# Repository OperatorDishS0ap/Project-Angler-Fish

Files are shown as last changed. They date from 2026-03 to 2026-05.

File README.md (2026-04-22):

  
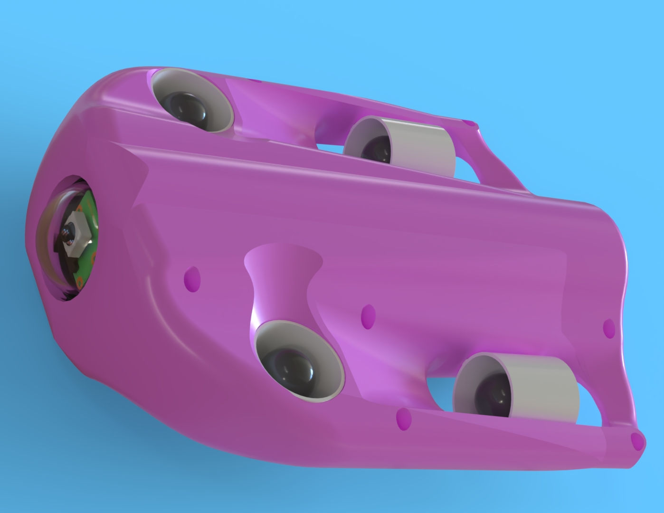
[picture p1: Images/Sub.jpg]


# Technical Details
23.5cm Long X 11cm Wide  
100ft depth rating  
Low-Latency Live Camera View  
Intuitive Control with an Xbox360 Controller 
Temperature and Depth Monitoring
Tethered Via Ethernet

# Introduction
Remotely operated vehicles (ROVs) are widely used for underwater research, inspection, and exploration; however, many commercially available systems remain prohibitively expensive for small research teams, educational institutions, and independent developers. This project explores the feasibility of designing and developing a cost-effective, remotely operated submersible capable of supporting underwater exploration while maintaining essential functionality and reliability.  
The system consists of a tethered ROV that provides four-axis maneuverability and a real-time first-person-view (FPV) video feed for navigation and situational awareness. Communication between the submersible and the surface control station is achieved through an Ethernet tether, enabling bidirectional control signals and continuous live video transmission.  
The project integrates mechanical design, electrical system development, and embedded software to implement propulsion control, sensor monitoring, and remote operation. Testing demonstrates that the vehicle is capable of stable maneuvering and reliable communication with the surface station while delivering continuous video feedback for navigation.  
To promote accessibility and encourage further development, all design files, software, assembly documentation, and technical resources associated with this project are released as open-source materials. These resources allow others to replicate, modify, and expand upon the system using accessible components and tools.   

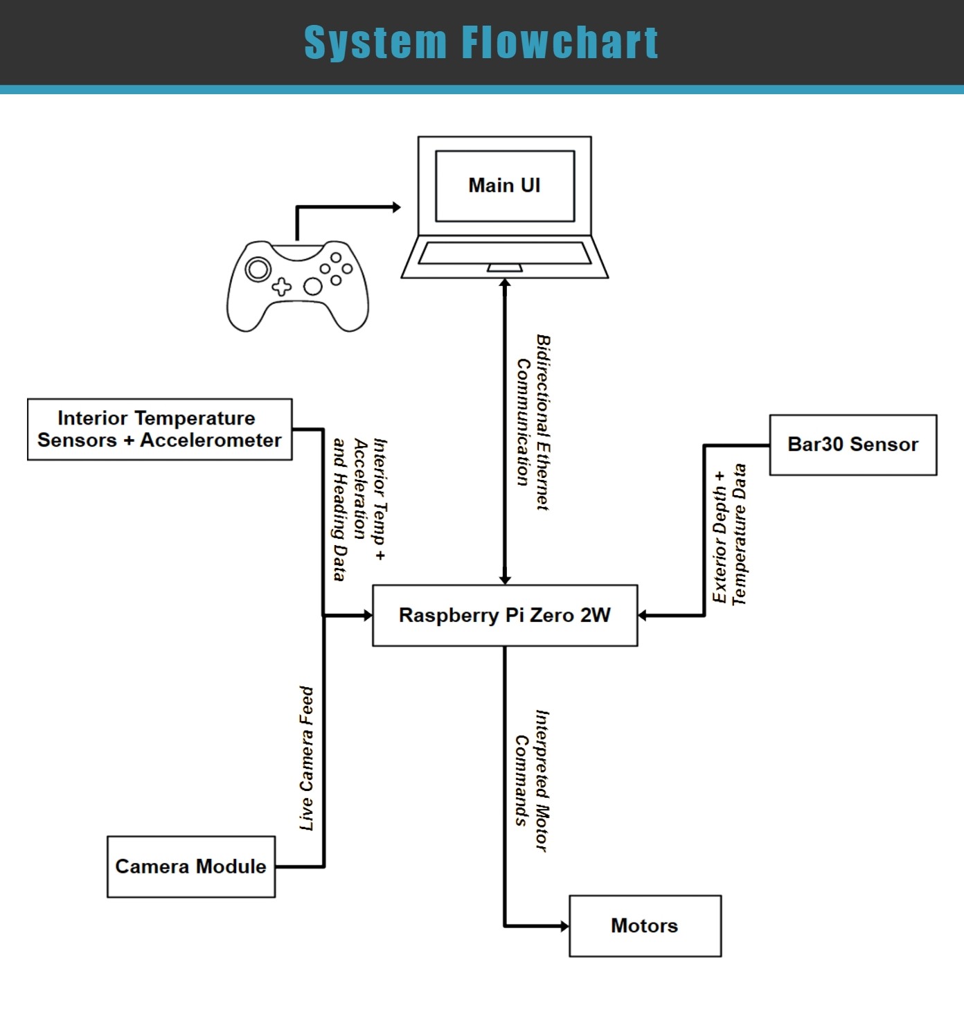
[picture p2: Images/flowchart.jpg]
flowchart
  
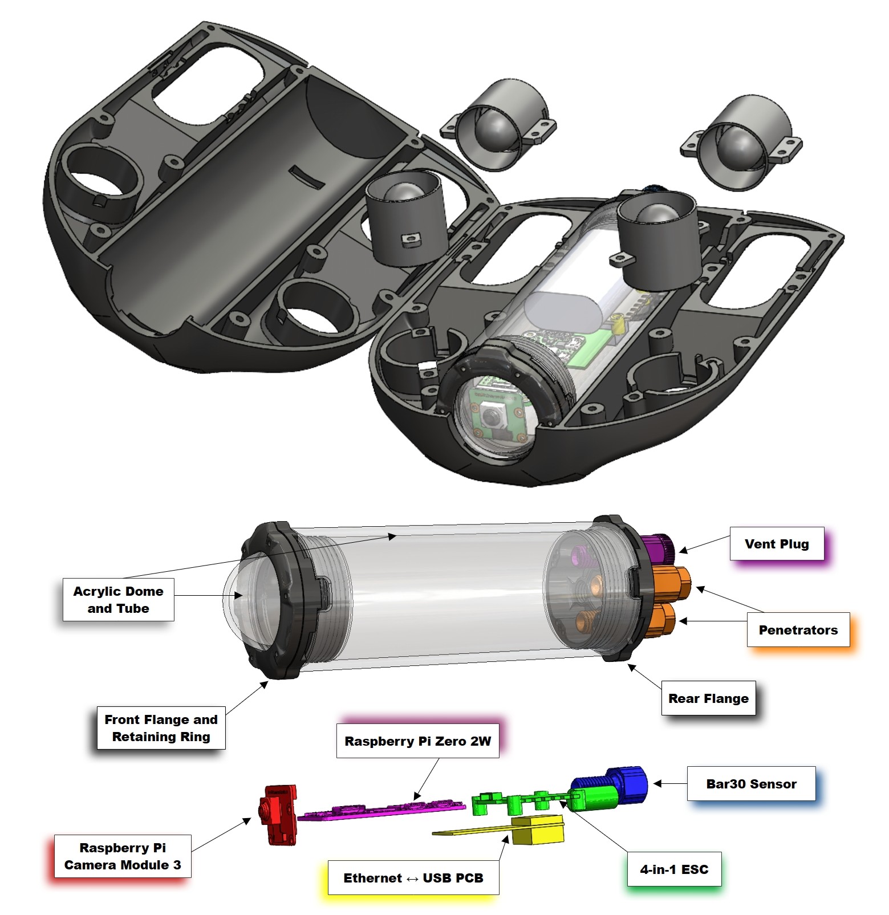
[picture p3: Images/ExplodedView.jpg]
explodedview
  

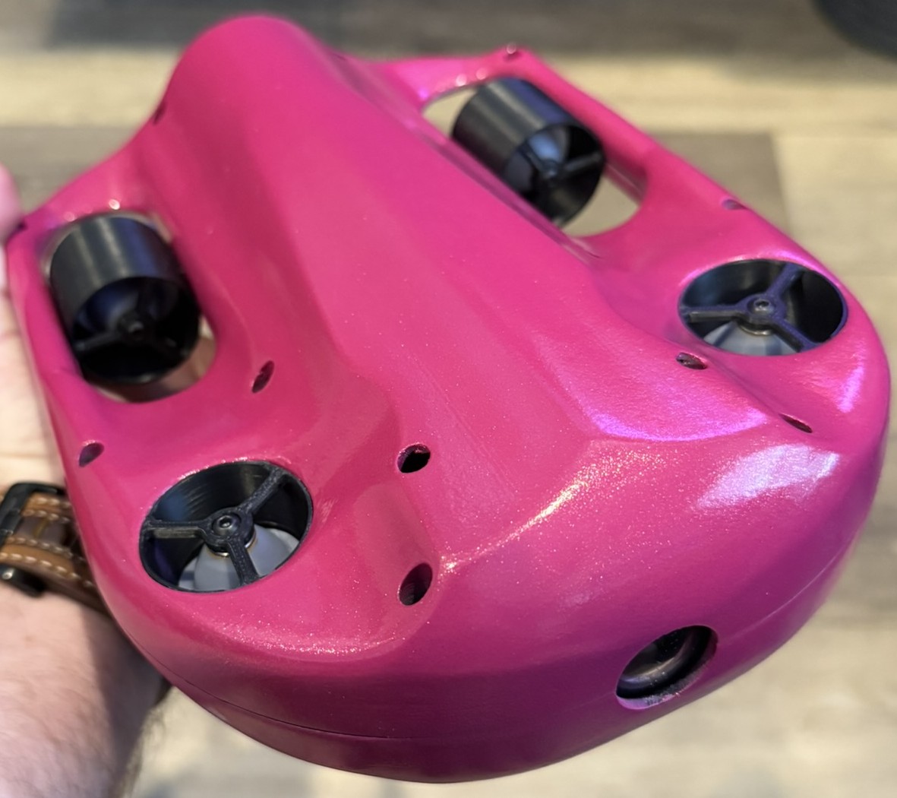
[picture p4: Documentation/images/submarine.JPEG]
Submarine

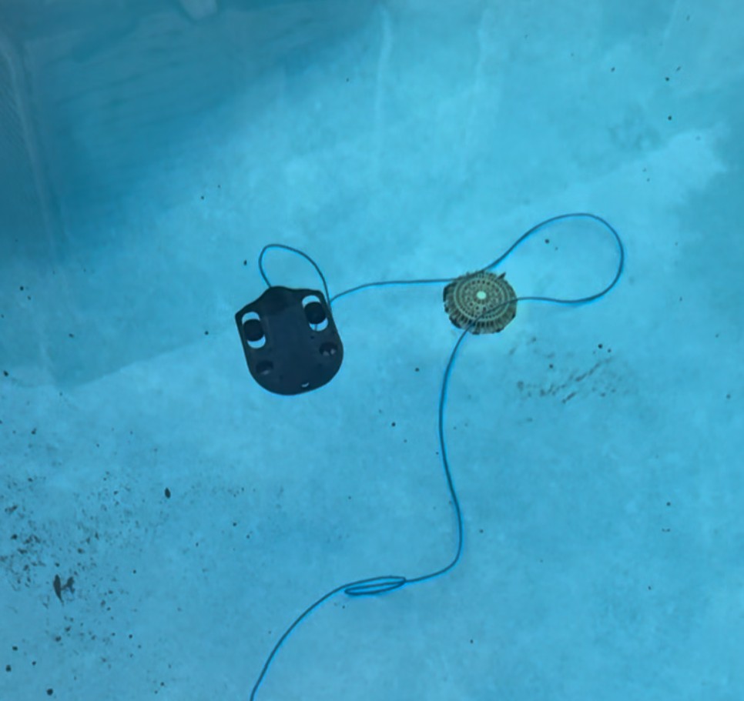
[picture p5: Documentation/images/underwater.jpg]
Submarine in the Pool

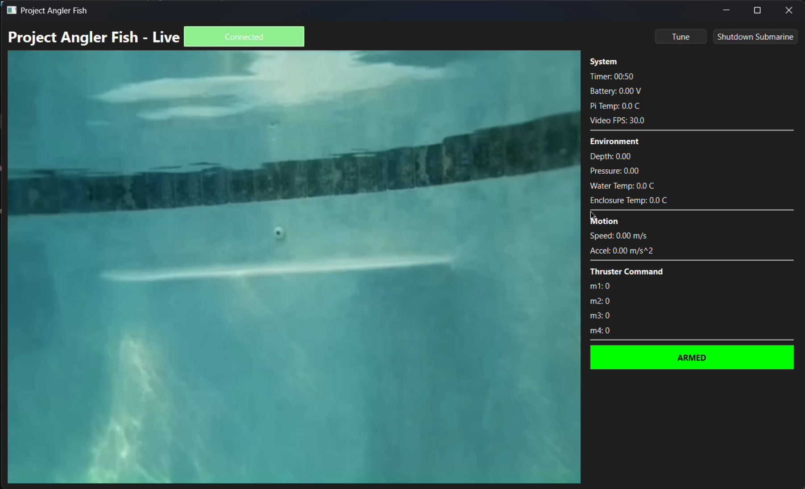
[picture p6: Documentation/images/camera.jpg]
Camera View


This Project is a Student Senior Capstone Project for the University of West Florida, Hal Marcus College of Science and Engineering  
UWF  

This Project was Funded and Supported by The HSU Family Educational Foundation Inc
HSULogo

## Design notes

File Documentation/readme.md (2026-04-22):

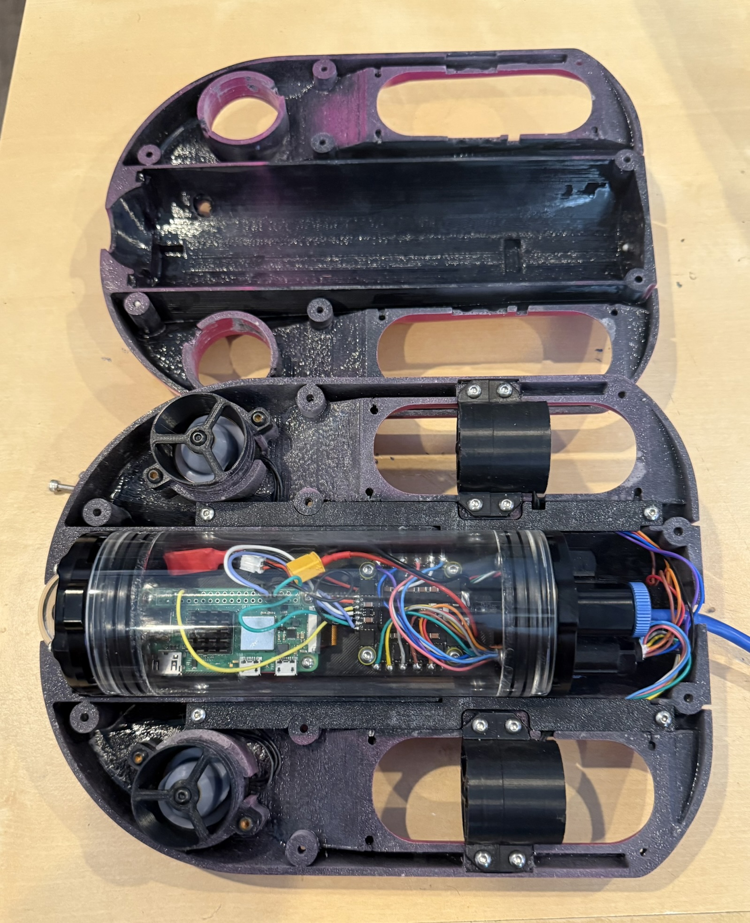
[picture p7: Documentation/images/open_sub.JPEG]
Open Submarine

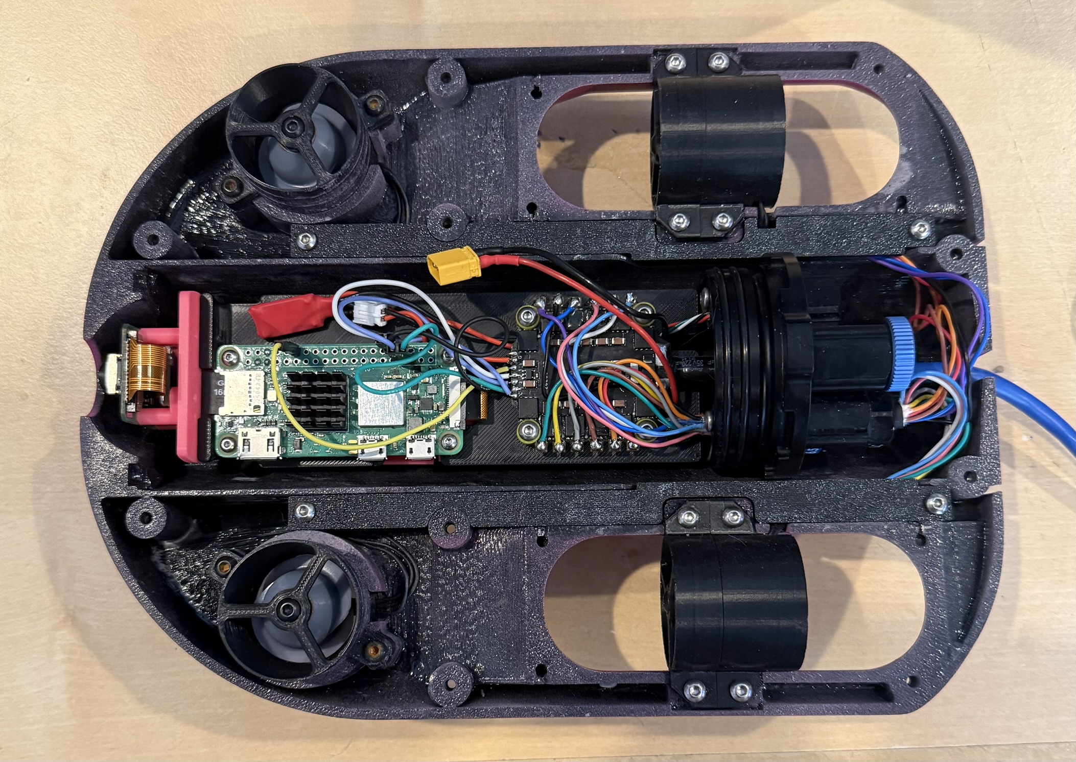
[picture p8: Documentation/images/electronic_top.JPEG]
Top Electronics

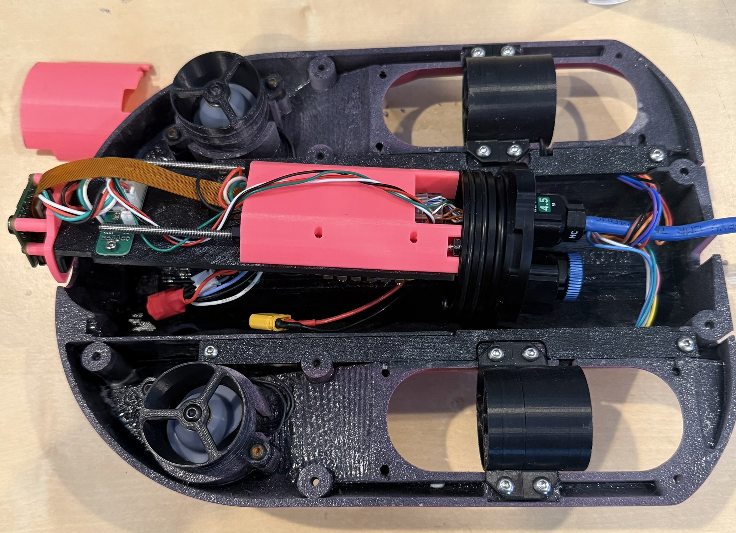
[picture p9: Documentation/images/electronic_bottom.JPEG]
Bottom Electronics

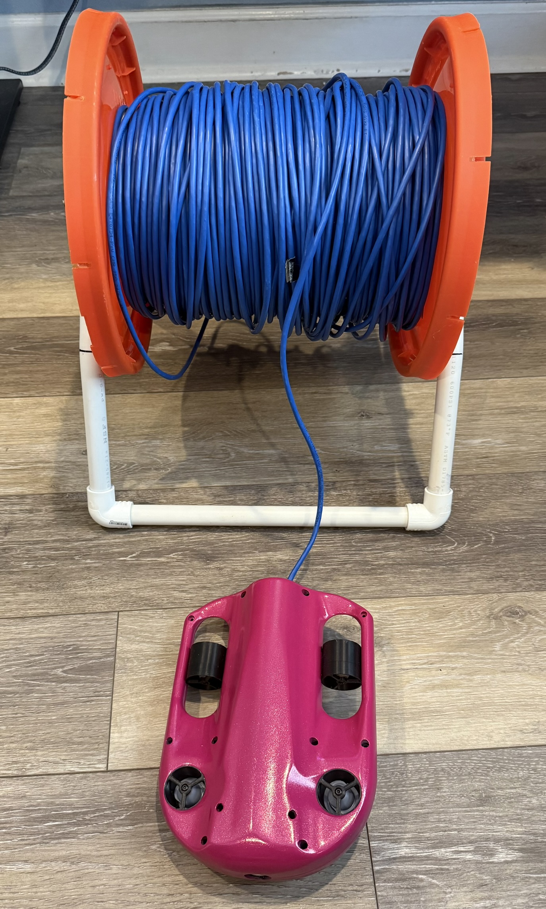
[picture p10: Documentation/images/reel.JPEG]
Cable Reel

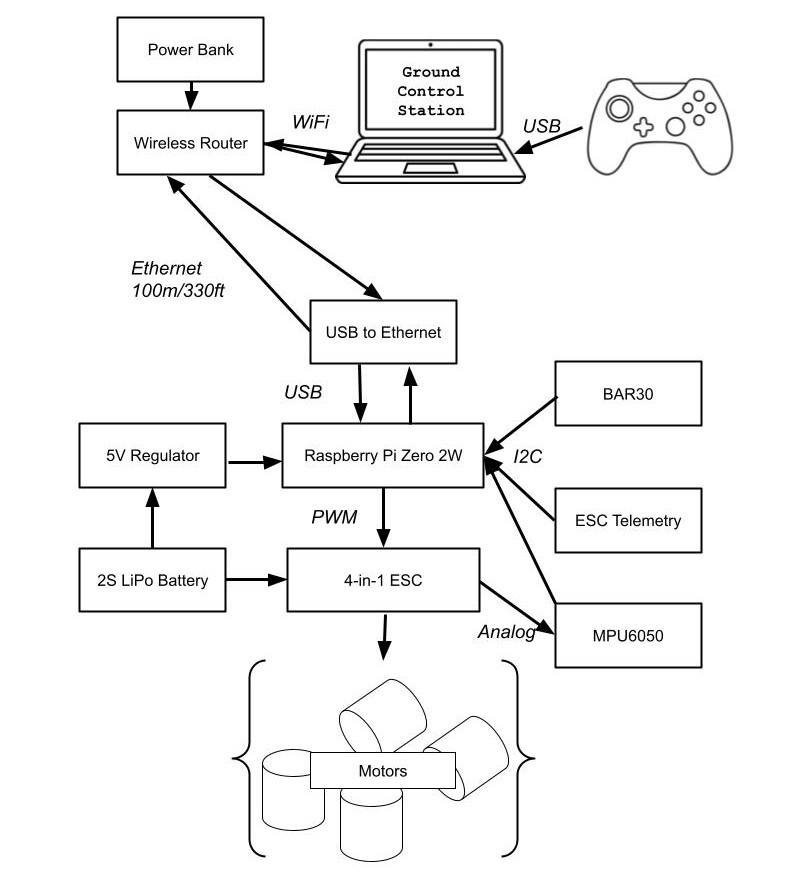
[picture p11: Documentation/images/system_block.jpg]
System Block Diagram

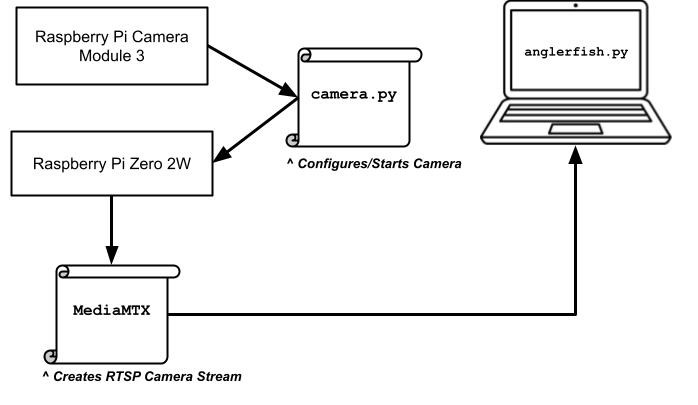
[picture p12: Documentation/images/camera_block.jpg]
Camera Block Diagram

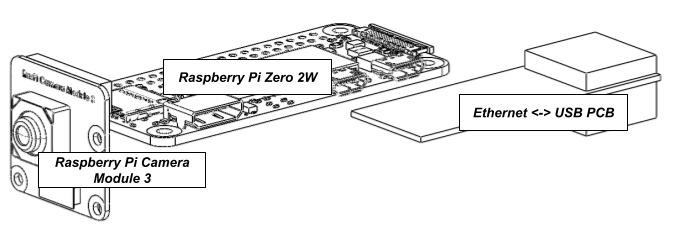
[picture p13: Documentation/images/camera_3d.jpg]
Camera Hardware

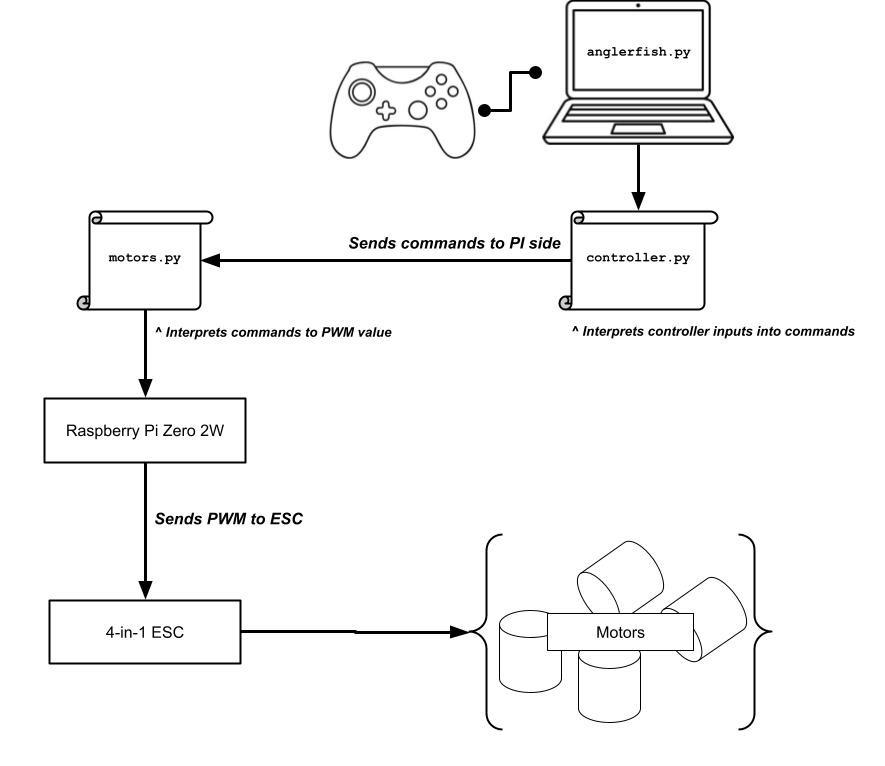
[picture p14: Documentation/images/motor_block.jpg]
Motor Block Diagram

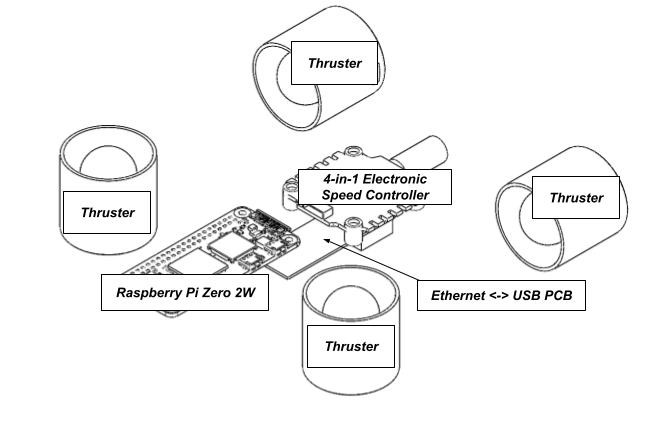
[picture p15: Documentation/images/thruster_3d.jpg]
Motor Hardware

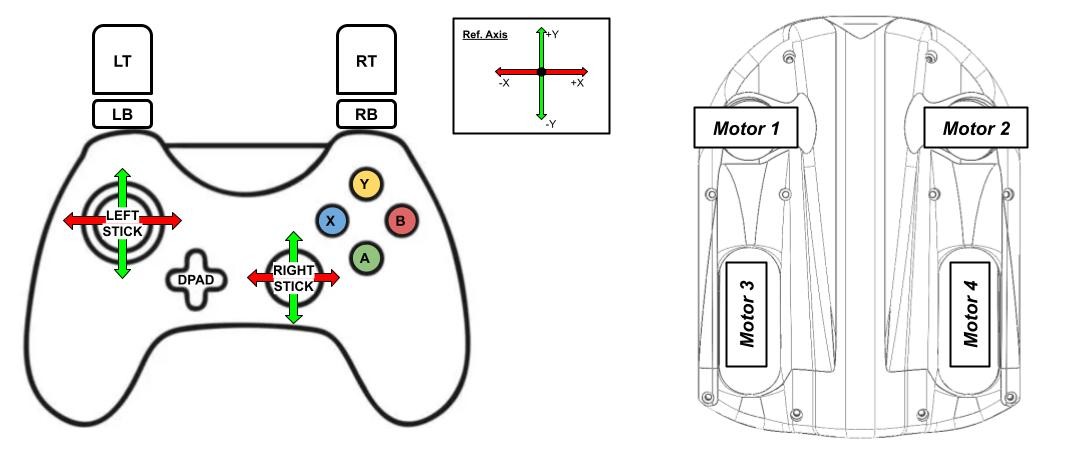
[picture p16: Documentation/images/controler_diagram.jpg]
Controller and Sub Diagram

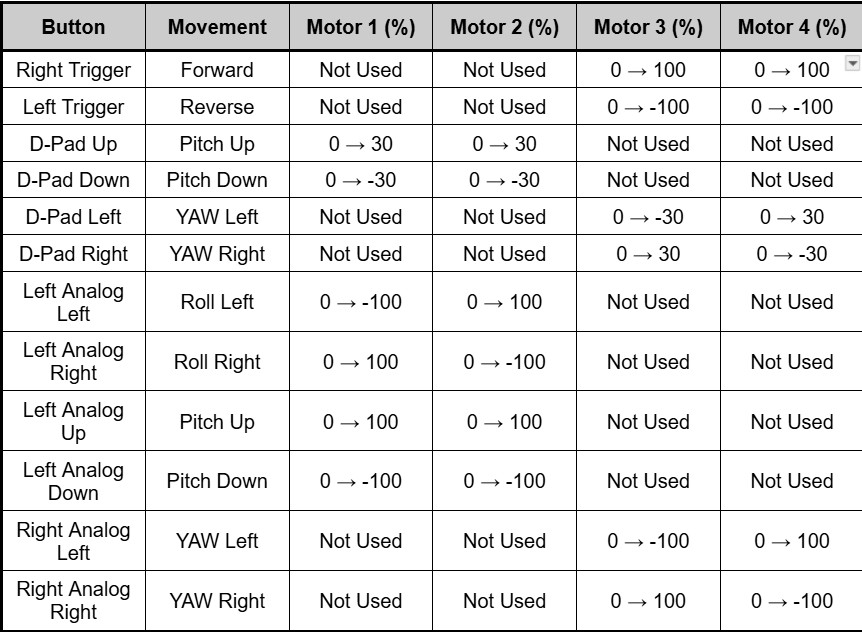
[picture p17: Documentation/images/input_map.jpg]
Input Mapping

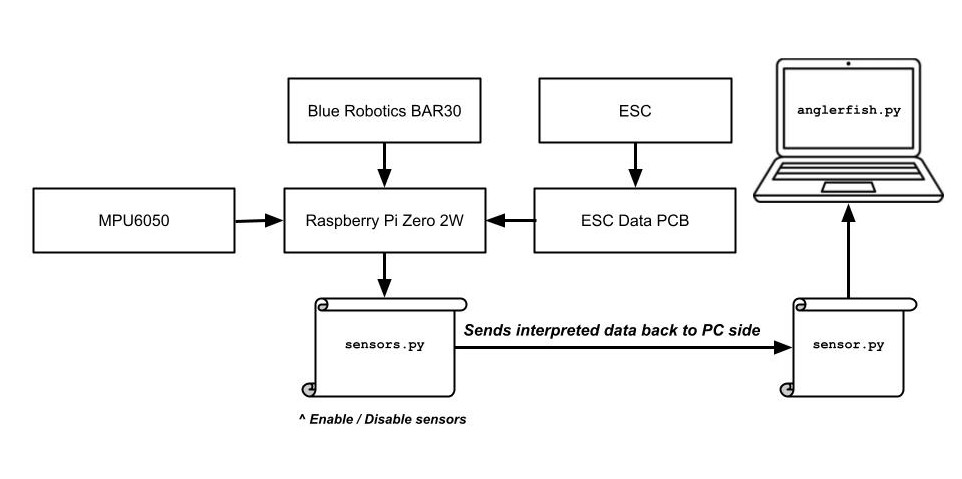
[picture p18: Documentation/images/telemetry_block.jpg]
Telemetry Block Diagram

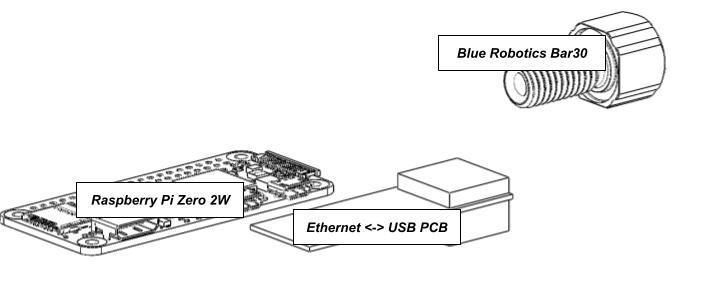
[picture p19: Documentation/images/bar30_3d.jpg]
BAR30 Harware

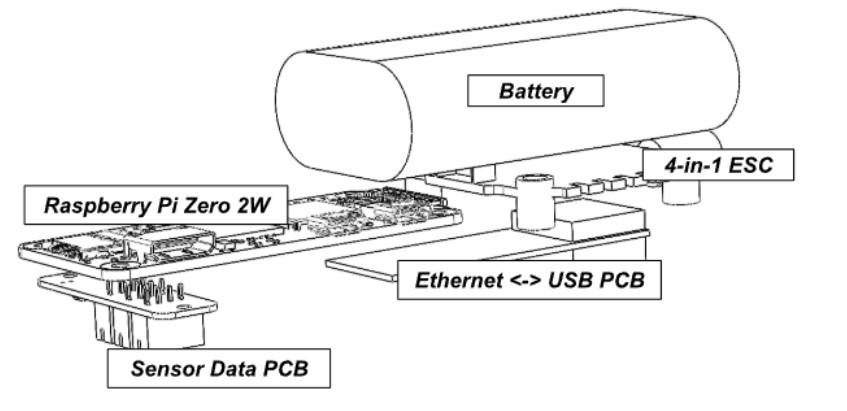
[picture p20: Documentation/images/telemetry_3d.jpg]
Battery Monitoring PCB

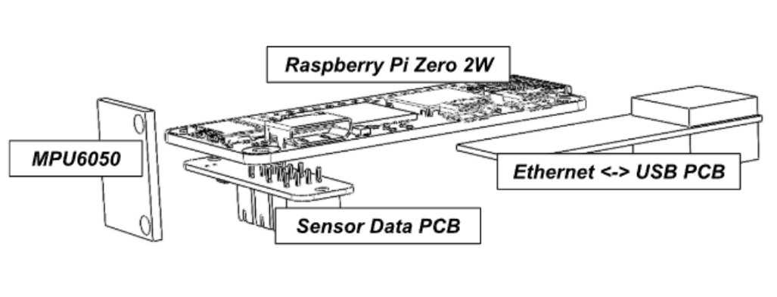
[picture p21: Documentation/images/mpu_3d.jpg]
Acclerometer and Gyroscope


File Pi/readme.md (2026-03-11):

For the Pi Zero 2W Submarine Controller

Install Raspberry Pi OS Lite (64bit)

From the terminal use this command to find the IP address of the PI
```
ping [hostname]
```
Example:
```
ping anglerfish
```

Connect to Pi via SSH

Update:
```
sudo apt update
sudo apt full-upgrade
```

Install Python Packages:
```
sudo apt install -y python3-paramiko python3-numpy python3-gpiozero python3-picamera2 python3-av python3-smbus
```

Install GStreamer
```
sudo apt install -y \
python3-gi \
python3-gst-1.0 \
gstreamer1.0-tools \
gstreamer1.0-plugins-base \
gstreamer1.0-plugins-good \
gstreamer1.0-plugins-bad \
gstreamer1.0-libav
sudo apt install gstreamer1.0-plugins-ugly
sudo apt install -y \
gir1.2-gst-rtsp-server-1.0 \
libgstrtspserver-1.0-0
```

Install git:
```
sudo apt install -y git
```
Install pigpio
```
sudo apt install -y python3-setuptools python3-full
wget https://github.com/joan2937/pigpio/archive/refs/tags/v79.tar.gz
tar zxf v79.tar.gz
cd pigpio-79
make
sudo make install
sudo ldconfig
sudo systemctl daemon-reload
```
Execute to start pigpio:
```
sudo pigpiod
```

Add Files:
```
git clone --filter=blob:none --no-checkout https://github.com/OperatorDishS0ap/Project-Angler-Fish.git
cd Project-Angler-Fish
git sparse-checkout init --cone
git sparse-checkout set Pi
git checkout main
```

To Update Files:
```
cd ~/Project-Angler-Fish
git pull
```
Given the files are corrupted or changed on the raspberry pi delete the the folder and re-add the repository files.
You can delete the folder from the home directory with the command:
```
rm -rf Project-Angler-Fish
```

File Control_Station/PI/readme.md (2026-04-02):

# Raspberry Pi 2W Submarine Controller Setup:

Install Raspberry Pi OS Lite (64bit) Trixie

From the terminal use this command to Connect to Pi via SSH
```
ssh [user]@[hostname]
```

Example:
```
ssh pi@anglerfish.local
```

Enter the config section:
```
sudo raspi-config
```
Go to Interface Options, I2C, Enable. Proceed to update the PI and finish when done.  

Determine the PI ip address:
```
ifconfig
```

Open the anglerfish control station. Input the ip address, the username, and the password. Under the tools section select create sub and wait for the installation to finish. The system will automatically reboot the PI. Once the PI reboots and starts the programs, the control station will connect to the sub.

# Dependencies:
### Only For troubleshooting
Install git:
```
sudo apt install -y git
```
Install pigpio
```
sudo apt install -y python3-setuptools python3-full
wget https://github.com/joan2937/pigpio/archive/refs/tags/v79.tar.gz
tar zxf v79.tar.gz
cd pigpio-79
make
sudo make install
sudo ldconfig
sudo systemctl daemon-reload
```
Use "sudo pigpiod" to start pigpio service for troubleshooting. The program will automatically start this service.  
Exit the directory to return to the home directory:
```
cd ..
```

Install MediaMTX:
```
mkdir -p ~/mediamtx
cd ~/mediamtx
wget https://github.com/bluenviron/mediamtx/releases/download/v1.17.0/mediamtx_v1.17.0_linux_arm64.tar.gz
tar -xzf mediamtx_v1.17.0_linux_arm64.tar.gz
chmod +x mediamtx
```
Create Config File:
```
rm mediamtx.yml
nano ~/mediamtx/mediamtx.yml
```
Paste in the new mediamtx.yml file:
```
logLevel: info

# Disable unused stuff (reduces errors + CPU)
rtmp: no
hls: no
webrtc: no
srt: no

paths:
  cam:
    source: publisher
```
Exit the directory to return to the home directory:
```
cd ..
```

Install Python Packages:
```
sudo apt install -y  python3-picamera2 python3-smbus python3-pip
sudo pip3 install adafruit-circuitpython-ads1x15 --break-system-packages
```

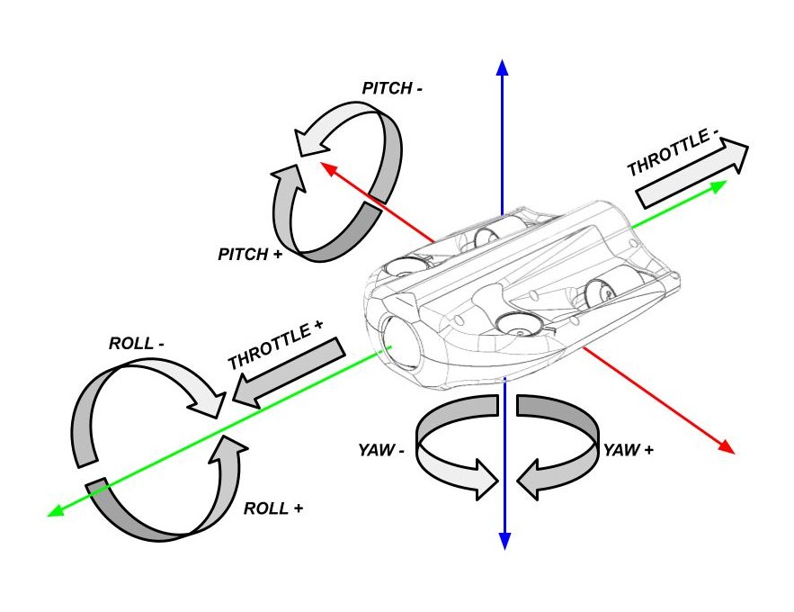
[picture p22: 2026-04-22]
Documentation/images/sub_movement.jpg

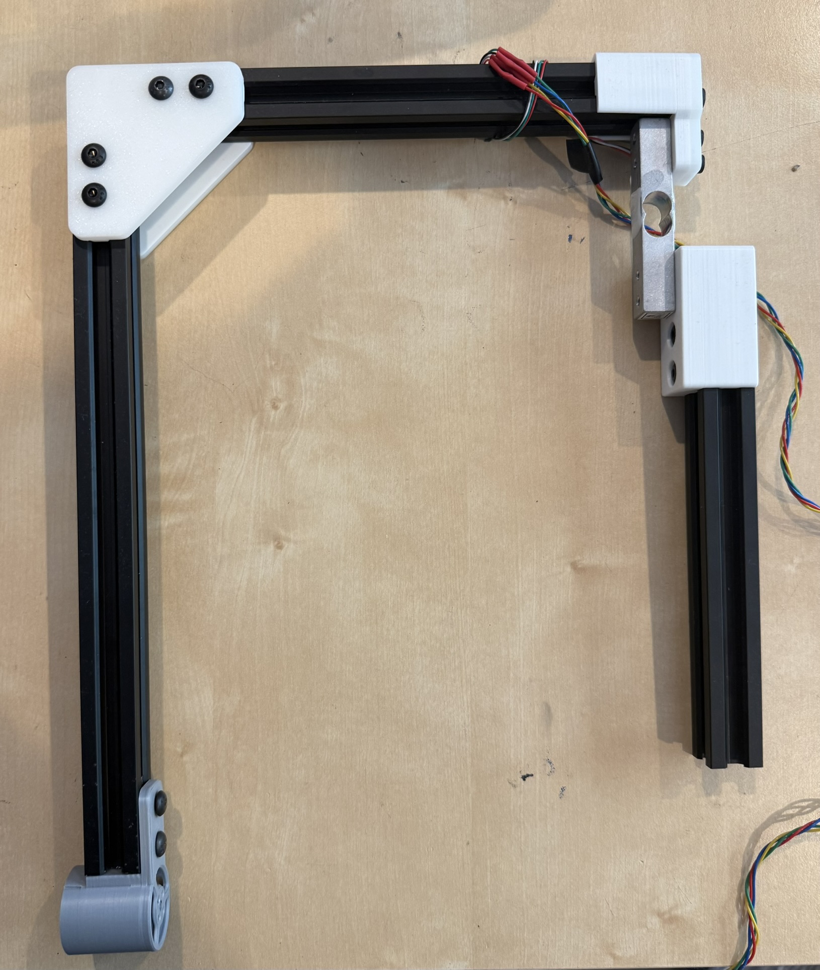
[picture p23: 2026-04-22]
Documentation/images/motor_stand.JPEG

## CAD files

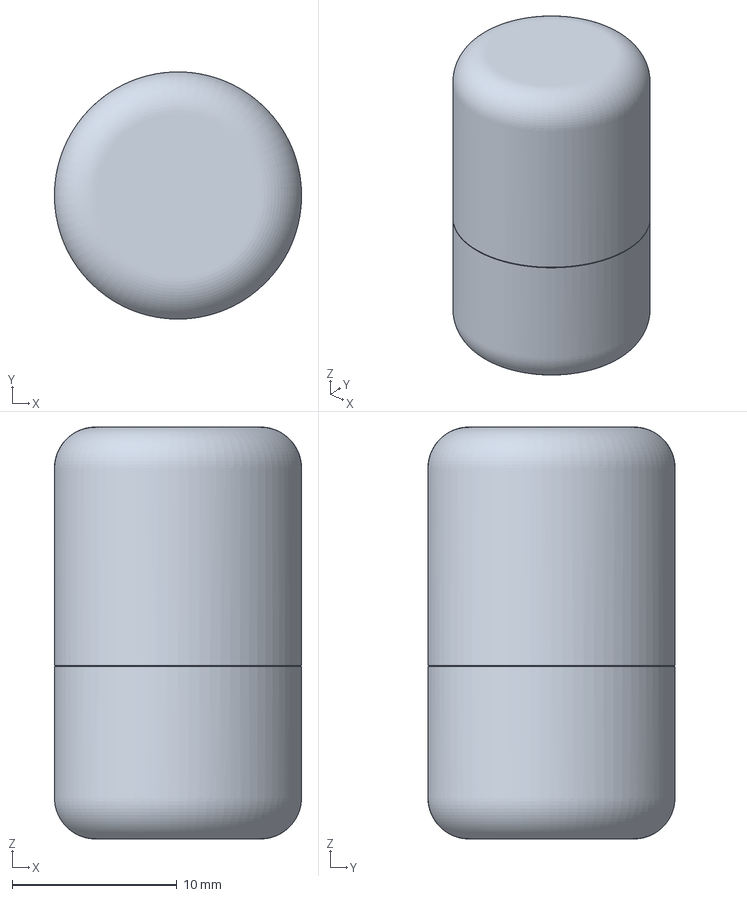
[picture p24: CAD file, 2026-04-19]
3D/STL/AirPod.3MF
15.0 x 15.0 x 25.0 mm

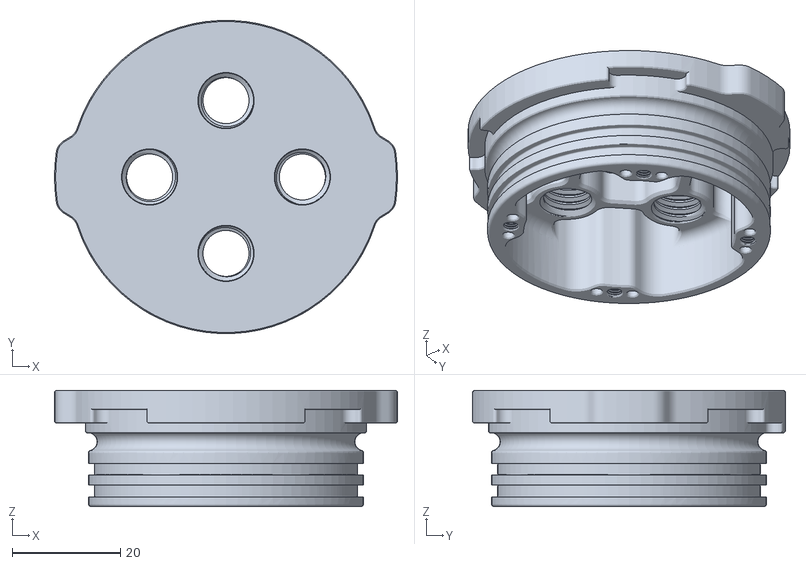
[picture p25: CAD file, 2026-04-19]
3D/STL/Enclosure/BackCap.STL
63.5 x 57.9 x 21.5

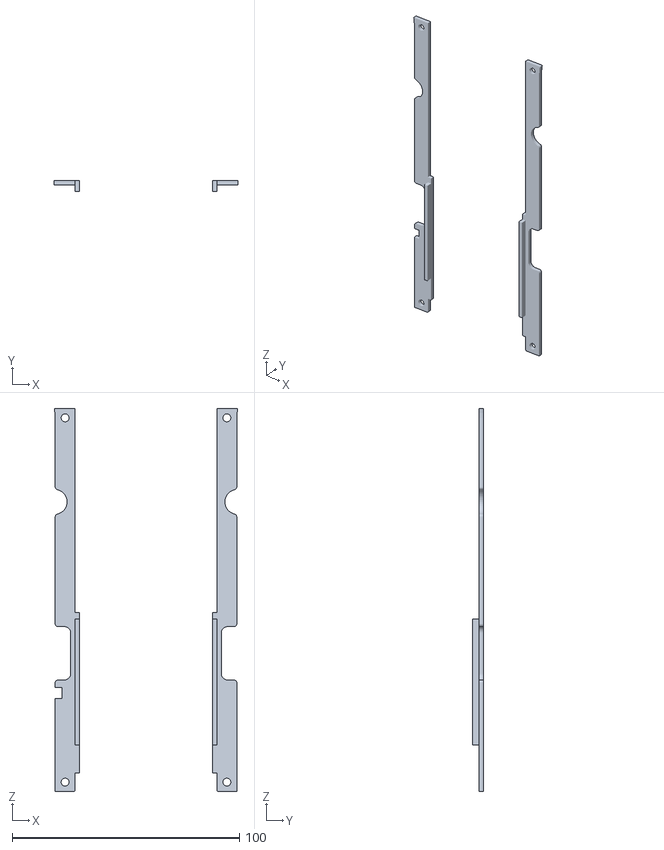
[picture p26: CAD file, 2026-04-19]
3D/STL/Shell/WireCover.STL
80.8 x 5.00 x 168.7

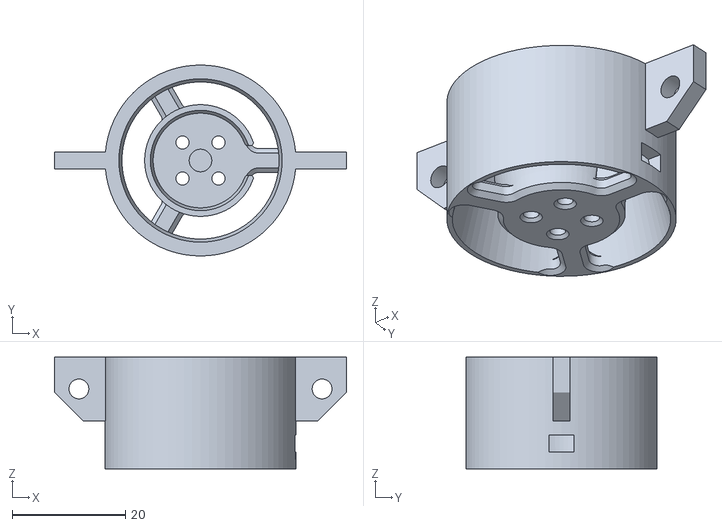
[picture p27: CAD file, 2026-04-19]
3D/STL/Thruster/RearHousingBottom.STL
51.6 x 33.8 x 19.8

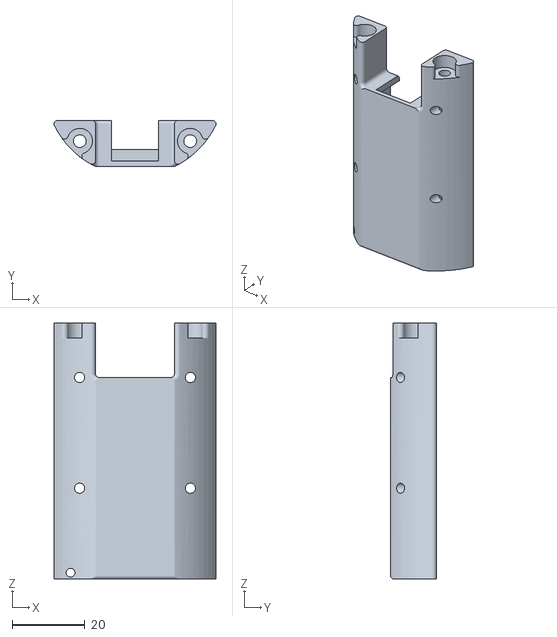
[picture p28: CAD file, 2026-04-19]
3D/STL/Enclosure/EthernetRack.STL
44.6 x 12.7 x 70.5

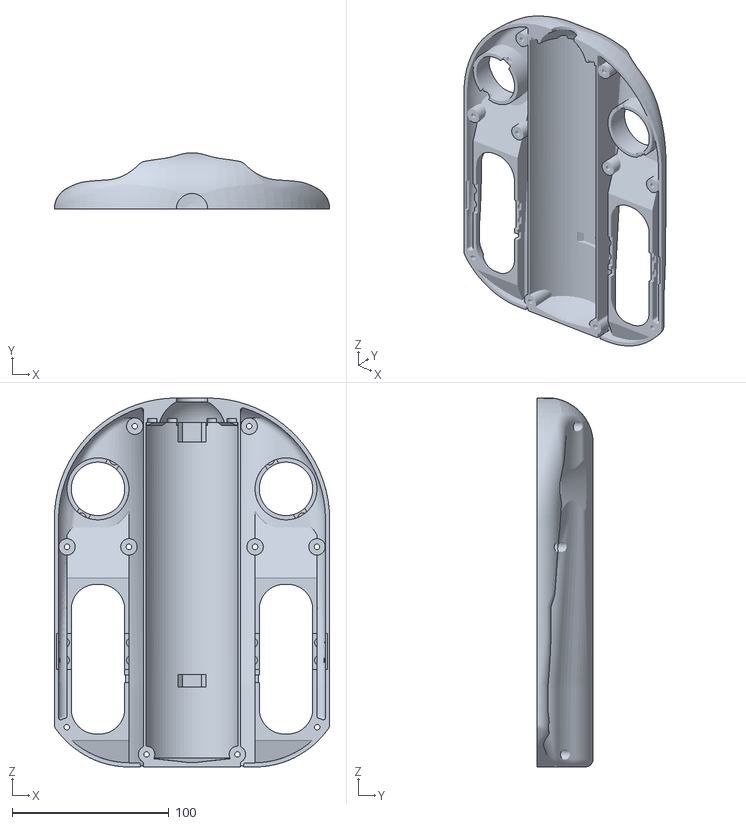
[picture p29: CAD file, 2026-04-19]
3D/STL/Shell/Top_Shell.STL
175.8 x 35.9 x 235.5

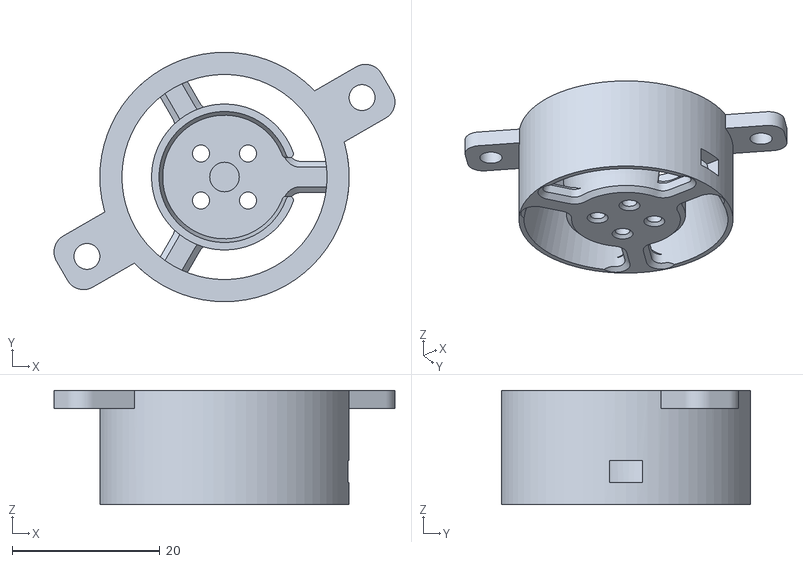
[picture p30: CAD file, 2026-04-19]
3D/STL/Thruster/FrontRightHousingBottom.STL
46.2 x 33.8 x 15.5

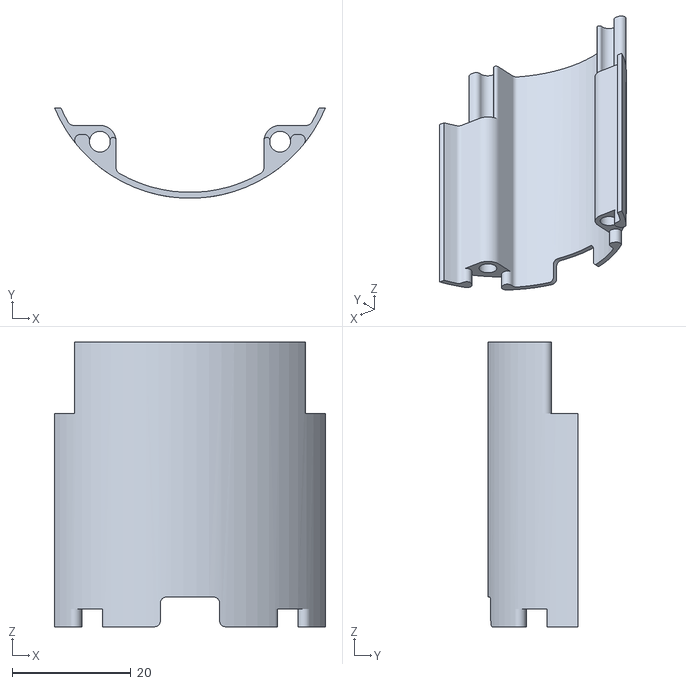
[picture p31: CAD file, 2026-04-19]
3D/STL/Enclosure/FrontCover.STL
45.7 x 15.2 x 48.0

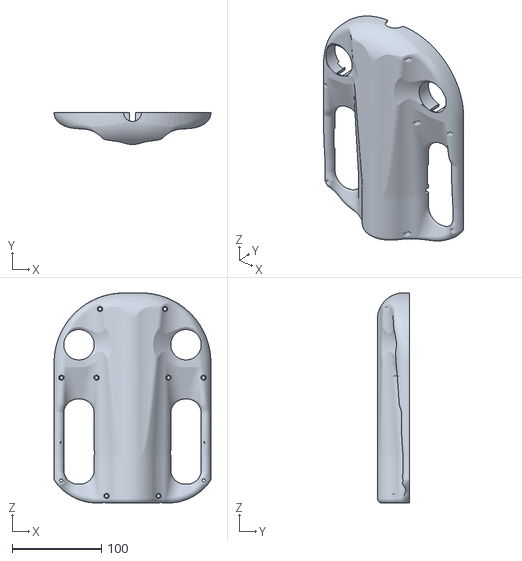
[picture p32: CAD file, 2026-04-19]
3D/STL/Shell/Bottom_Shell.STL
175.8 x 35.9 x 235.5

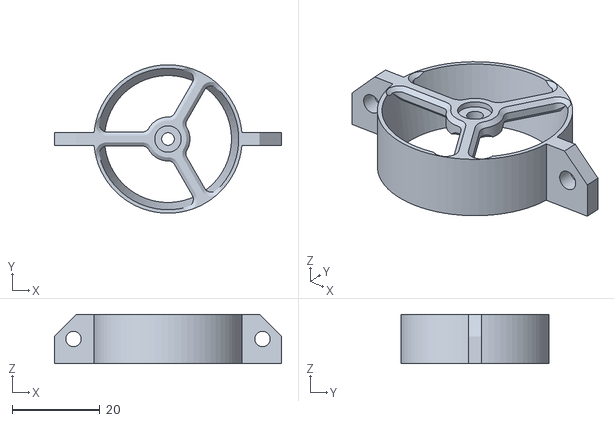
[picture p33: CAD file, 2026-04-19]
3D/STL/Thruster/RearHousingTop.STL
51.6 x 33.8 x 11.2

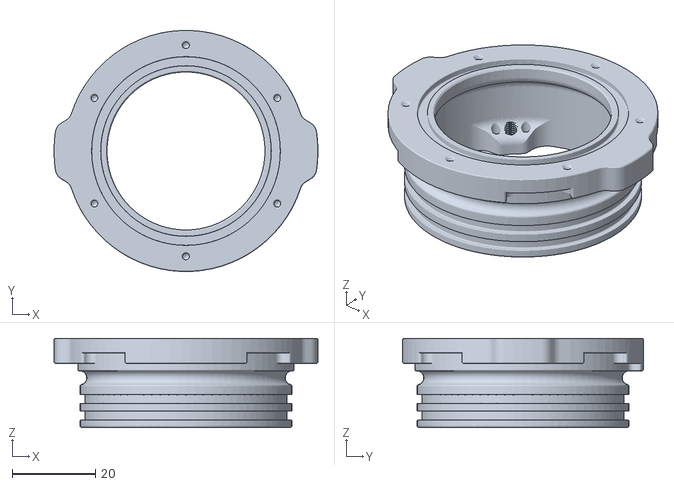
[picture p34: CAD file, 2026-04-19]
3D/STL/Enclosure/FrontCap.STL
63.5 x 57.9 x 21.5

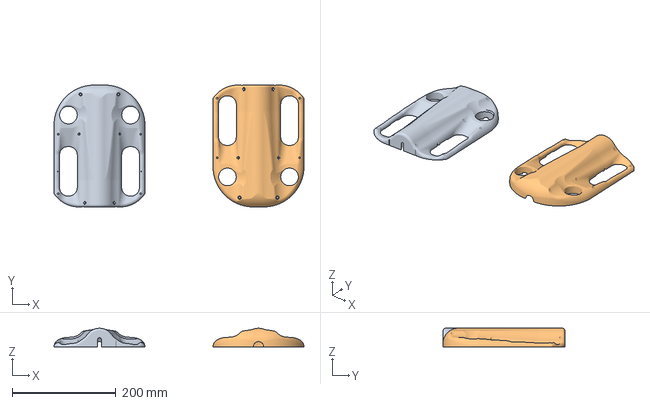
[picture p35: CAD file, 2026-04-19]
3D/STL/Shell/Shell_BambuSlicer.3mf
483.0 x 235.5 x 35.9 mm
Bottom_Shell.STL
Top_Shell.STL

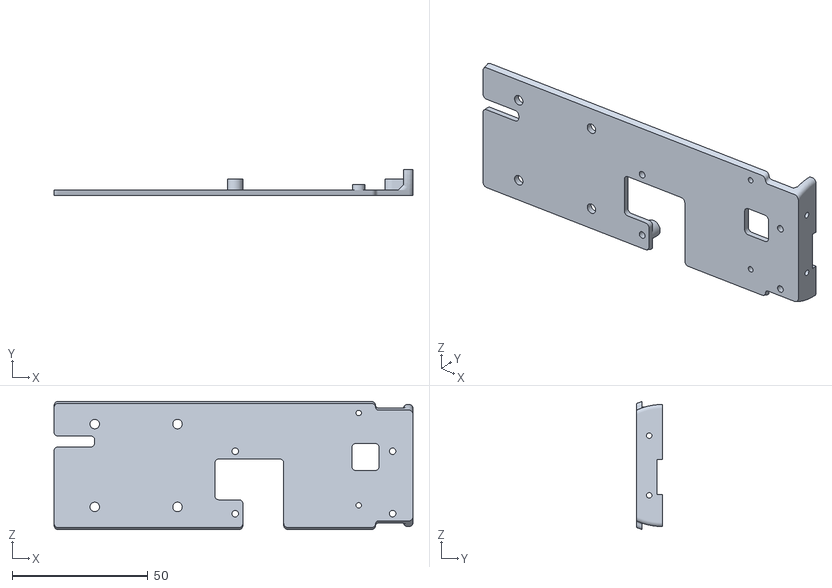
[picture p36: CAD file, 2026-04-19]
3D/STL/Enclosure/CenterPlate.STL
132.3 x 9.50 x 47.2

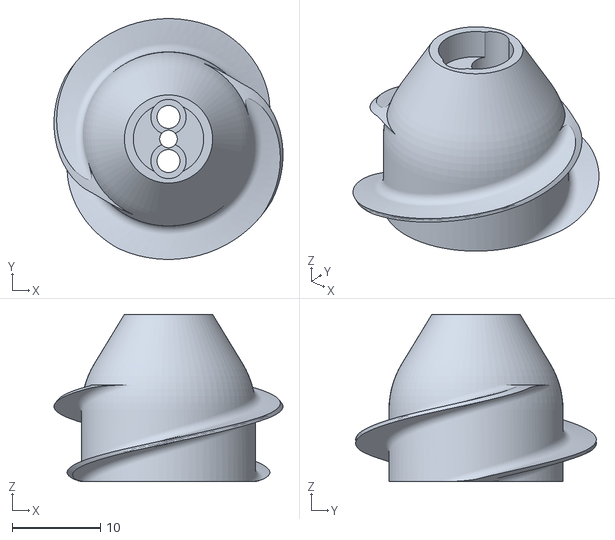
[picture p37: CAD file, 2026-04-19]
3D/STL/Thruster/PropV3CW.STL
26.0 x 27.3 x 19.0

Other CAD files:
3D/STL/Thruster/FrontLeftHousingBottom.STL
3D/STL/Enclosure/RetainingRing.STL
3D/STL/Thruster/PropV3CCW.STL
3D/STL/Enclosure/CameraMount.STL
3D/STL/Thruster/FrontLeftHousingTop.STL
3D/STL/Thruster/FrontRightHousingTop.STL

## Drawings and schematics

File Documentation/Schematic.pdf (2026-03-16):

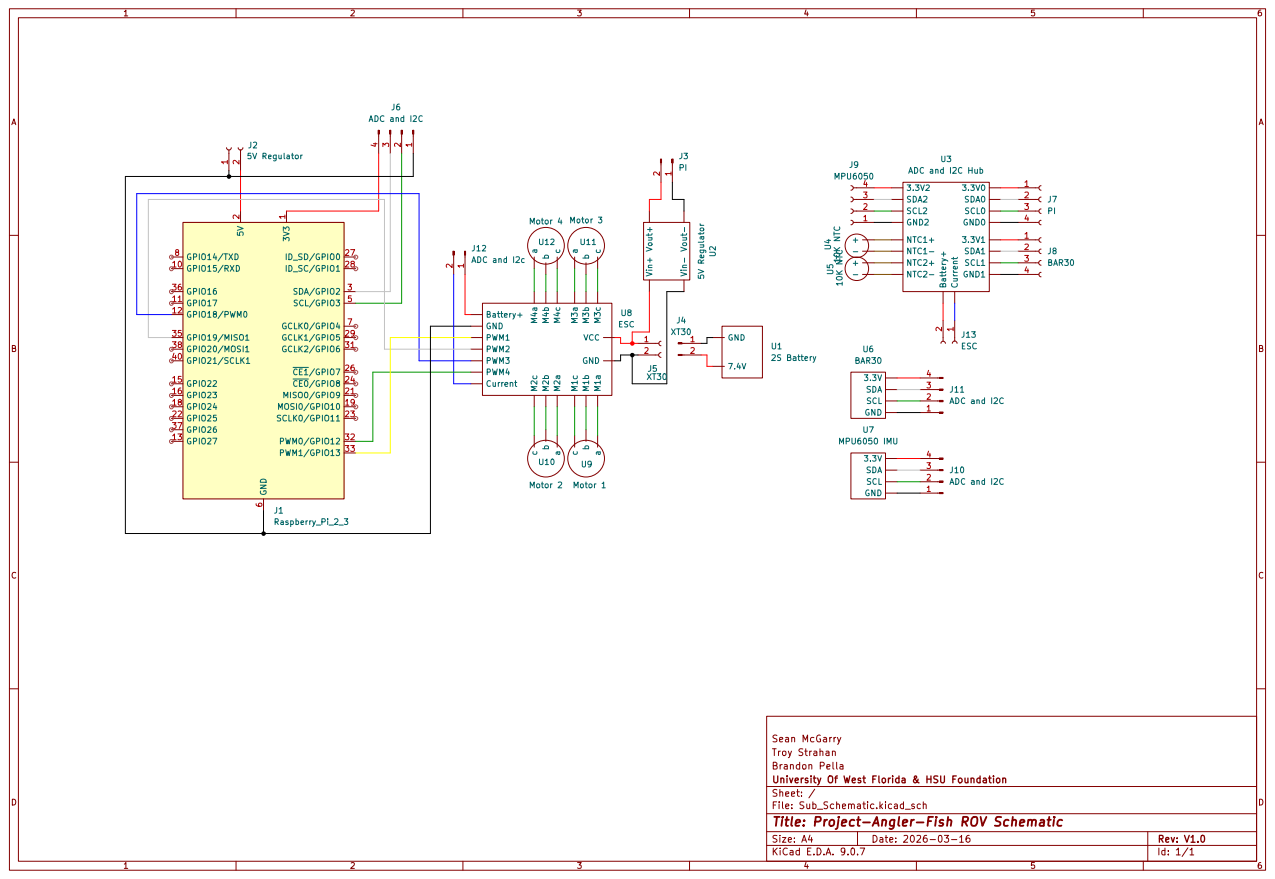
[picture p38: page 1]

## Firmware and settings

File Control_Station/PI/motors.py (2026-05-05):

import json
import socket
import struct
import time
import os
import fcntl
import pigpio

# -------------------------
# NETWORK
# -------------------------
LISTEN_IP = "0.0.0.0"
LISTEN_PORT = 9000
SOCK_TIMEOUT_S = 0.2

# -------------------------
# GPIO MAP
# -------------------------
GPIO_M1 = 19
GPIO_M2 = 13
GPIO_M3 = 18
GPIO_M4 = 12
ALL_GPIOS = (GPIO_M1, GPIO_M2, GPIO_M3, GPIO_M4)

# -------------------------
# ESC / PWM SETTINGS
# -------------------------
ESC_FREQ_HZ = 400
PERIOD_US = int(1_000_000 / ESC_FREQ_HZ)  # 2500us @ 400Hz
PWM_RANGE = PERIOD_US                      # range=2500 => dutycycle "counts" == microseconds

PULSE_MIN = 1350
PULSE_MAX = 1650

PULSE_NEUTRAL = 1460

AVOID_LO = 1410
AVOID_HI = 1510
FORWARD_START = AVOID_HI + 1

ARM_TIME_S = 3.0
LOOP_SLEEP_S = 0.005
COMMAND_TIMEOUT_S = 1.0
LOCK_PATH = "/tmp/anglerfish_motors.lock"
POWER_STATE_PATH = os.environ.get("ANGLERFISH_POWER_STATE_PATH", "/tmp/anglerfish_power_state.json")
POWER_STATE_CHECK_S = float(os.environ.get("ANGLERFISH_POWER_STATE_CHECK_S", "0.01"))
PITCH_KP = float(os.environ.get("ANGLERFISH_STABILIZATION_PITCH_KP", "0.5"))
PITCH_KD = float(os.environ.get("ANGLERFISH_STABILIZATION_PITCH_KD", "0.5"))
ROLL_KP = float(os.environ.get("ANGLERFISH_STABILIZATION_ROLL_KP", "0.1"))
ROLL_KD = float(os.environ.get("ANGLERFISH_STABILIZATION_ROLL_KD", "0.5"))
ANGLE_ERROR_MARGIN_PCT = float(os.environ.get("ANGLERFISH_STABILIZATION_ERROR_MARGIN_PCT", "5.0"))
ROLL_ANGLE_ERROR_MARGIN_MIN_DEG = float(
    os.environ.get(
        "ANGLERFISH_STABILIZATION_ROLL_ERROR_MARGIN_MIN_DEG",
        os.environ.get("ANGLERFISH_STABILIZATION_ERROR_MARGIN_MIN_DEG", "3.0"),
    )
)
PITCH_ANGLE_ERROR_MARGIN_MIN_DEG = float(
    os.environ.get("ANGLERFISH_STABILIZATION_PITCH_ERROR_MARGIN_MIN_DEG", "3.0")
)
STABILIZE_TARGET_PITCH_DEG = float(os.environ.get("ANGLERFISH_STABILIZATION_TARGET_PITCH_DEG", "0.0"))
STABILIZE_TARGET_ROLL_DEG = float(os.environ.get("ANGLERFISH_STABILIZATION_TARGET_ROLL_DEG", "0.0"))
STABILIZATION_MAX_PCT = float(os.environ.get("ANGLERFISH_STABILIZATION_MAX_PCT", "15.0"))
STABILIZATION_SLEW_STEP_PCT = float(os.environ.get("ANGLERFISH_STABILIZATION_SLEW_STEP_PCT", "1.0"))

# Small command deadband: treat tiny commands as neutral
PCT_DEADBAND = 2.0  # percent

# -------------------------
# LEGACY BINARY PROTOCOL
# -------------------------
CMD_FMT = "<4sI5h"
CMD_FMT_OLD = "<4sI4h"
CMD_MAGIC = b"SUB1"
CMD_SIZE = struct.calcsize(CMD_FMT)
CMD_SIZE_OLD = struct.calcsize(CMD_FMT_OLD)


def clamp(v, lo, hi):
    return max(lo, min(hi, v))


def apply_error_margin(error_deg: float, target_deg: float, margin_pct: float, min_margin_deg: float) -> float:
    margin_deg = max(abs(target_deg) * (margin_pct / 100.0), min_margin_deg)
    if abs(error_deg) <= margin_deg:
        return 0.0
    return error_deg


def mix_stabilization_motors(pitch_command: float, roll_command: float):
    m3 = clamp(-pitch_command - roll_command, -STABILIZATION_MAX_PCT, STABILIZATION_MAX_PCT)
    m4 = clamp(-pitch_command + roll_command, -STABILIZATION_MAX_PCT, STABILIZATION_MAX_PCT)
    return m3, m4


def acquire_single_instance_lock(lock_path: str):
    lock_file = open(lock_path, "w")
    try:
        fcntl.flock(lock_file.fileno(), fcntl.LOCK_EX | fcntl.LOCK_NB)
    except BlockingIOError:
        lock_file.close()
        raise SystemExit("Another motors.py instance is already running")
    lock_file.write(str(os.getpid()))
    lock_file.flush()
    return lock_file


def connect_pigpio_with_retry(retries: int = 5, delay_s: float = 0.5) -> pigpio.pi:
    last_pi = None
    for _ in range(retries):
        pi = pigpio.pi()
        last_pi = pi
        if pi.connected:
            return pi
        try:
            pi.stop()
        except Exception:
            pass
        time.sleep(delay_s)
    if last_pi is not None:
        try:
            last_pi.stop()
        except Exception:
            pass
    raise SystemExit("pigpio daemon not running or unstable. Start with: sudo systemctl restart pigpiod")


def pigpio_call(pi: pigpio.pi, method_name: str, *args):
    method = getattr(pi, method_name)
    try:
        return pi, method(*args)
    except (BrokenPipeError, OSError):
        try:
            pi.stop()
        except Exception:
            pass
        time.sleep(0.2)
        pi = connect_pigpio_with_retry(retries=5, delay_s=0.3)
        method = getattr(pi, method_name)
        return pi, method(*args)


def i16_to_pct(v_i16: int) -> float:
    # -1000..+1000 => -100..+100
    return clamp((float(v_i16) / 1000.0) * 100.0, -100.0, 100.0)


def pct_to_pulse_us(pct: float, pulse_min_us: int, pulse_max_us: int) -> int:
    pct = clamp(pct, -100.0, 100.0)

    if abs(pct) <= PCT_DEADBAND:
        return PULSE_NEUTRAL

    pulse_min_us = int(clamp(pulse_min_us, 1000, AVOID_LO))
    pulse_max_us = int(clamp(pulse_max_us, AVOID_HI, 2000))

    if pct < 0:
        # Reverse: jump just below the avoid zone, then scale toward pulse_min_us.
        # Mirrors the forward path which jumps to FORWARD_START to skip the avoid zone.
        # Without this, small reverse commands land inside the avoid zone and get reset to neutral.
        return int(AVOID_LO + (pulse_min_us - AVOID_LO) * (abs(pct) / 100.0))

    # Forward: +0% => FORWARD_START (just above avoid zone), +100% => pulse_max_us
    return int(FORWARD_START + (pulse_max_us - FORWARD_START) * (pct / 100.0))


def setup_pwm_esc(pi: pigpio.pi, gpio: int):
    pi, _ = pigpio_call(pi, "set_mode", gpio, pigpio.OUTPUT)

    # Ensure servo mode is off (servo mode is ~50Hz)
    pi, _ = pigpio_call(pi, "set_servo_pulsewidth", gpio, 0)

    # Configure PWM
    pi, _ = pigpio_call(pi, "set_PWM_frequency", gpio, ESC_FREQ_HZ)
    pi, _ = pigpio_call(pi, "set_PWM_range", gpio, PWM_RANGE)

    # Neutral output to arm
    pi, _ = pigpio_call(pi, "set_PWM_dutycycle", gpio, PULSE_NEUTRAL)
    return pi


def set_pulse_us(pi: pigpio.pi, gpio: int, pulse_us: int, pulse_min_us: int, pulse_max_us: int):
    pulse_us = int(pulse_us)

    # Avoid creep zone (1501..1600)
    if AVOID_LO < pulse_us <= AVOID_HI:
        pulse_us = PULSE_NEUTRAL

    pulse_min_us = int(clamp(pulse_min_us, 1000, AVOID_LO))
    pulse_max_us = int(clamp(pulse_max_us, AVOID_HI, 2000))
    pulse_us = clamp(pulse_us, pulse_min_us, pulse_max_us)
    pi, _ = pigpio_call(pi, "set_PWM_dutycycle", gpio, pulse_us)
    return pi


def read_power_state(path: str):
    try:
        with open(path, "r", encoding="utf-8") as fh:
            data = json.load(fh)
        if not isinstance(data, dict):
            return {}
        return data
    except Exception:
        return {}


def main():
    lock_file = acquire_single_instance_lock(LOCK_PATH)
    pi = connect_pigpio_with_retry()

    # Setup all ESC outputs
    for g in ALL_GPIOS:
        pi = setup_pwm_esc(pi, g)

    # Debug: confirm PWM config (PWM mode; do NOT call get_servo_pulsewidth)
    for g in ALL_GPIOS:
        pi, pwm_freq = pigpio_call(pi, "get_PWM_frequency", g)
        pi, pwm_range = pigpio_call(pi, "get_PWM_range", g)
        pi, duty = pigpio_call(pi, "get_PWM_dutycycle", g)
        print(
            f"GPIO {g}: pwm_freq={pwm_freq}Hz "
            f"pwm_range={pwm_range} duty={duty}"
        )

    print(f"[sub_motors_400hz] Arming at neutral ({PULSE_NEUTRAL}us) for {ARM_TIME_S:.1f}s ...")
    time.sleep(ARM_TIME_S)

    # UDP socket
    sock = socket.socket(socket.AF_INET, socket.SOCK_DGRAM)
    sock.bind((LISTEN_IP, LISTEN_PORT))
    sock.settimeout(SOCK_TIMEOUT_S)

    last = {"m1": 0.0, "m2": 0.0, "m3": 0.0, "m4": 0.0}
    arm_requested = False
    arm_active = False
    arm_started_at = None
    last_command_ts = time.time()
    pulse_min_us = PULSE_MIN
    pulse_max_us = PULSE_MAX
    esc_overtemp_active = False
    last_esc_temp_c = None
    last_power_state_check = 0.0
    attitude_ready = False
    pitch_deg = 0.0
    roll_deg = 0.0
    pitch_rate_dps = 0.0
    roll_rate_dps = 0.0
    stabilize_horizontal = False
    last_stabilize_horizontal = False
    home_pitch_offset_deg = 0.0
    home_roll_offset_deg = 0.0
    imu_home_requested = False
    stabilize_m3_last = 0.0
    stabilize_m4_last = 0.0

    print(f"[sub_motors_400hz] Listening UDP on {LISTEN_IP}:{LISTEN_PORT}")

    try:
        while True:
            # Receive
            try:
                data, _addr = sock.recvfrom(2048)

                # 1) Legacy binary
                if len(data) >= CMD_SIZE_OLD and data[:4] == CMD_MAGIC:
                    if len(data) >= CMD_SIZE:
                        magic, _seq, m1_i16, m2_i16, m3_i16, m4_i16, arm_i16 = struct.unpack(CMD_FMT, data[:CMD_SIZE])
                    else:
                        magic, _seq, m1_i16, m2_i16, m3_i16, m4_i16 = struct.unpack(CMD_FMT_OLD, data[:CMD_SIZE_OLD])
                        arm_i16 = 1000  # Backward-compatible: old packets are treated as armed.

                    if magic != CMD_MAGIC:
                        raise ValueError("Not legacy magic")

                    last = {
                        "m1": i16_to_pct(m1_i16),
                        "m2": i16_to_pct(m2_i16),
                        "m3": i16_to_pct(m3_i16),
                        "m4": i16_to_pct(m4_i16),
                    }
                    arm_requested = arm_i16 > 0
                    last_command_ts = time.time()

                else:
                    # JSON fallback
                    msg = json.loads(data.decode("utf-8", errors="ignore"))

                    if msg.get("type") == "tune":
                        if "pulse_min_us" in msg:
                            pulse_min_us = int(clamp(float(msg["pulse_min_us"]), 1000, AVOID_LO))
                        if "pulse_max_us" in msg:
                            pulse_max_us = int(clamp(float(msg["pulse_max_us"]), AVOID_HI, 2000))

                        if pulse_min_us >= pulse_max_us:
                            pulse_min_us = min(pulse_min_us, AVOID_LO)
                            pulse_max_us = max(pulse_max_us, AVOID_HI)
                        print(f"[sub_motors_400hz] Tune update: PULSE_MIN={pulse_min_us} PULSE_MAX={pulse_max_us}")
                    else:
                        last = {
                            "m1": float(msg.get("m1", last["m1"])),
                            "m2": float(msg.get("m2", last["m2"])),
                            "m3": float(msg.get("m3", last["m3"])),
                            "m4": float(msg.get("m4", last["m4"])),
                        }
                        arm_requested = bool(msg.get("arm", arm_requested))
                        stabilize_horizontal = bool(msg.get("stabilize_horizontal", stabilize_horizontal))
                        if bool(msg.get("imu_home", False)):
                            imu_home_requested = True
                        last_command_ts = time.time()

                        if stabilize_horizontal != last_stabilize_horizontal:
                            if stabilize_horizontal:
                                print(
                                    f"[sub_motors_400hz] Horizontal stabilization ENABLED "
                                    f"(target_pitch={STABILIZE_TARGET_PITCH_DEG:.2f}, target_roll={STABILIZE_TARGET_ROLL_DEG:.2f})"
                                )
                            else:
                                print("[sub_motors_400hz] Horizontal stabilization DISABLED")
                            last_stabilize_horizontal = stabilize_horizontal


            except socket.timeout:
                pass
            except Exception:
                pass

            now = time.time()
            if (now - last_power_state_check) >= max(0.005, POWER_STATE_CHECK_S):
                last_power_state_check = now
                power_state = read_power_state(POWER_STATE_PATH)
                esc_overtemp_state = bool(power_state.get("esc_overtemp_active", False))
                esc_max_temp_c = power_state.get("esc_max_temp_c")
                attitude_ready = bool(power_state.get("attitude_ready", False))
                pitch_deg = float(power_state.get("pitch_deg", 0.0) or 0.0)
                roll_deg = float(power_state.get("roll_deg", 0.0) or 0.0)
                pitch_rate_dps = float(power_state.get("pitch_rate_dps", 0.0) or 0.0)
                roll_rate_dps = float(power_state.get("roll_rate_dps", 0.0) or 0.0)
                if esc_max_temp_c is not None:
                    try:
                        last_esc_temp_c = float(esc_max_temp_c)
                    except Exception:
                        pass

                if esc_overtemp_state and not esc_overtemp_active:
                    msg_t = f"{last_esc_temp_c:.2f}C" if last_esc_temp_c is not None else "unknown temp"
                    print(f"[sub_motors_400hz] ESC overtemp ACTIVE ({msg_t}); motor output blocked.")
                elif (not esc_overtemp_state) and esc_overtemp_active:
                    msg_t = f"{last_esc_temp_c:.2f}C" if last_esc_temp_c is not None else "unknown temp"
                    print(f"[sub_motors_400hz] ESC overtemp CLEARED ({msg_t}); motor output allowed.")
                esc_overtemp_active = esc_overtemp_state

                if imu_home_requested:
                    if attitude_ready:
                        home_pitch_offset_deg = pitch_deg
                        home_roll_offset_deg = roll_deg
                        print(
                            "[sub_motors_400hz] IMU homed "
                            f"(pitch_offset={home_pitch_offset_deg:.2f}, roll_offset={home_roll_offset_deg:.2f})"
                        )
                    else:
                        print("[sub_motors_400hz] IMU home requested but attitude is not ready")
                    imu_home_requested = False

            if (time.time() - last_command_ts) > COMMAND_TIMEOUT_S:
                arm_requested = False
                last = {"m1": 0.0, "m2": 0.0, "m3": 0.0, "m4": 0.0}

            if esc_overtemp_active:
                arm_requested = False
                last = {"m1": 0.0, "m2": 0.0, "m3": 0.0, "m4": 0.0}

            # Arm/disarm state machine for ESC safety.
            if not arm_requested:
                if arm_active:
                    print("[sub_motors_400hz] DISARM command received; forcing neutral.")
                arm_active = False
                arm_started_at = None
                last = {"m1": 0.0, "m2": 0.0, "m3": 0.0, "m4": 0.0}
            else:
                if arm_started_at is None:
                    arm_started_at = time.time()
                    arm_active = False
                    print(f"[sub_motors_400hz] ARM command received; holding neutral for {ARM_TIME_S:.1f}s.")
                elif not arm_active and (time.time() - arm_started_at) >= ARM_TIME_S:
                    arm_active = True
                    print("[sub_motors_400hz] ESC output armed.")

            output = dict(last)
            manual_attitude_override = abs(output["m3"]) > PCT_DEADBAND or abs(output["m4"]) > PCT_DEADBAND
            stabilization_active = arm_active and stabilize_horizontal and attitude_ready and not manual_attitude_override

            if stabilization_active:
                adjusted_pitch_deg = pitch_deg - home_pitch_offset_deg
                adjusted_roll_deg = roll_deg - home_roll_offset_deg
                pitch_error = apply_error_margin(
                    adjusted_pitch_deg - STABILIZE_TARGET_PITCH_DEG,
                    STABILIZE_TARGET_PITCH_DEG,
                    ANGLE_ERROR_MARGIN_PCT,
                    PITCH_ANGLE_ERROR_MARGIN_MIN_DEG,
                )
                roll_error = apply_error_margin(
                    adjusted_roll_deg - STABILIZE_TARGET_ROLL_DEG,
                    STABILIZE_TARGET_ROLL_DEG,
                    ANGLE_ERROR_MARGIN_PCT,
                    ROLL_ANGLE_ERROR_MARGIN_MIN_DEG,
                )
                pitch_command = (PITCH_KP * pitch_error) - (PITCH_KD * pitch_rate_dps)
                roll_command = (ROLL_KP * roll_error) - (ROLL_KD * roll_rate_dps)
                stabilize_m3, stabilize_m4 = mix_stabilization_motors(pitch_command, roll_command)

                # Rate-limit stabilization changes to reduce oscillation and overshoot.
                stabilize_m3 = clamp(
                    stabilize_m3,
                    stabilize_m3_last - STABILIZATION_SLEW_STEP_PCT,
                    stabilize_m3_last + STABILIZATION_SLEW_STEP_PCT,
                )
                stabilize_m4 = clamp(
                    stabilize_m4,
                    stabilize_m4_last - STABILIZATION_SLEW_STEP_PCT,
                    stabilize_m4_last + STABILIZATION_SLEW_STEP_PCT,
                )

                output["m3"] = clamp(output["m3"] + stabilize_m3, -STABILIZATION_MAX_PCT, STABILIZATION_MAX_PCT)
                output["m4"] = clamp(output["m4"] + stabilize_m4, -STABILIZATION_MAX_PCT, STABILIZATION_MAX_PCT)
                stabilize_m3_last = stabilize_m3
                stabilize_m4_last = stabilize_m4
            else:
                stabilize_m3_last = 0.0
                stabilize_m4_last = 0.0

            # Apply outputs (PWM @ 400Hz)
            if arm_active:
                pi = set_pulse_us(pi, GPIO_M1, pct_to_pulse_us(output["m1"], pulse_min_us, pulse_max_us), pulse_min_us, pulse_max_us)
                pi = set_pulse_us(pi, GPIO_M2, pct_to_pulse_us(output["m2"], pulse_min_us, pulse_max_us), pulse_min_us, pulse_max_us)
                pi = set_pulse_us(pi, GPIO_M3, pct_to_pulse_us(output["m3"], pulse_min_us, pulse_max_us), pulse_min_us, pulse_max_us)
                pi = set_pulse_us(pi, GPIO_M4, pct_to_pulse_us(output["m4"], pulse_min_us, pulse_max_us), pulse_min_us, pulse_max_us)
            else:
                for g in ALL_GPIOS:
                    pi = set_pulse_us(pi, g, PULSE_NEUTRAL, pulse_min_us, pulse_max_us)

            time.sleep(LOOP_SLEEP_S)

    finally:
        # Neutral on exit
        for g in ALL_GPIOS:
            pi = set_pulse_us(pi, g, PULSE_NEUTRAL, pulse_min_us, pulse_max_us)
        time.sleep(0.5)
        pi.stop()
        try:
            fcntl.flock(lock_file.fileno(), fcntl.LOCK_UN)
        except Exception:
            pass
        try:
            lock_file.close()
        except Exception:
            pass


if __name__ == "__main__":
    main()

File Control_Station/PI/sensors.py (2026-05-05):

#!/usr/bin/env python3
import json
import os
import random
import socket
import time
from typing import Optional
from bar30_sensor import init_bar30, read_bar30
from mpu6050_sensor import accel_to_pitch_roll, calibrate_gyro, init_imu_with_retry, read_imu
from ads1015_sensor import init_ads1015, read_ads1015

USE_BROADCAST = os.environ.get("ANGLERFISH_USE_BROADCAST", "1") == "1"
BROADCAST_IP = os.environ.get("ANGLERFISH_BROADCAST_IP", "255.255.255.255")
PC_IP = os.environ.get("ANGLERFISH_PC_IP", "192.168.137.1")  # used when ANGLERFISH_USE_BROADCAST=0
PC_PORT = int(os.environ.get("ANGLERFISH_PC_PORT", "9001"))
ENABLE_BAR30 = os.environ.get("ANGLERFISH_ENABLE_BAR30", "1") == "1"
ENABLE_MPU6050 = os.environ.get("ANGLERFISH_ENABLE_MPU6050", "1") == "1"
ENABLE_ADS1015 = os.environ.get("ANGLERFISH_ENABLE_ADS1015", "0") == "1"
DEBUG = os.environ.get("ANGLERFISH_SENSOR_DEBUG", "1") == "1"

TELEMETRY_SEND_HZ = float(os.environ.get("ANGLERFISH_TELEMETRY_SEND_HZ", "2.0"))
BAR30_HZ = float(os.environ.get("ANGLERFISH_BAR30_HZ", "2.0"))
MPU6050_HZ = float(os.environ.get("ANGLERFISH_MPU6050_HZ", "100.0"))
PI_TEMP_HZ = float(os.environ.get("ANGLERFISH_PI_TEMP_HZ", "2.0"))
BATTERY_HZ = float(os.environ.get("ANGLERFISH_BATTERY_HZ", "2.0"))
ADS1015_HZ = float(os.environ.get("ANGLERFISH_ADS1015_HZ", "8.0"))
ESC_OVERTEMP_C = float(os.environ.get("ANGLERFISH_ESC_OVERTEMP_C", "90.0"))
ESC_OVERTEMP_CLEAR_C = float(os.environ.get("ANGLERFISH_ESC_OVERTEMP_CLEAR_C", "85.0"))
BATTERY_EMA_ALPHA = float(os.environ.get("ANGLERFISH_BATTERY_EMA_ALPHA", "0.2"))
POWER_STATE_PATH = os.environ.get("ANGLERFISH_POWER_STATE_PATH", "/tmp/anglerfish_power_state.json")
COMPLEMENTARY_ALPHA = float(os.environ.get("ANGLERFISH_COMPLEMENTARY_ALPHA", "0.98"))
GYRO_CALIBRATION_SAMPLES = int(os.environ.get("ANGLERFISH_GYRO_CALIBRATION_SAMPLES", "200"))
GYRO_CALIBRATION_DELAY_S = float(os.environ.get("ANGLERFISH_GYRO_CALIBRATION_DELAY_S", "0.005"))


def _hz_to_interval(hz: float, min_hz: float = 0.1) -> float:
    return 1.0 / max(min_hz, hz)


def _ema(prev_value: Optional[float], sample: float, alpha: float) -> float:
    if prev_value is None:
        return float(sample)
    a = max(0.0, min(1.0, alpha))
    return (a * float(sample)) + ((1.0 - a) * float(prev_value))


def _initialize_attitude_state(imu_dev):
    if imu_dev is None:
        return 0.0, 0.0, {"x": 0.0, "y": 0.0, "z": 0.0}, False

    print("[sensors] Calibrating MPU6050 gyro; keep the ROV still and level...")
    try:
        gyro_bias = calibrate_gyro(
            imu_dev,
            samples=GYRO_CALIBRATION_SAMPLES,
            delay_s=GYRO_CALIBRATION_DELAY_S,
        )
        accel, _gyro, _imu_temp = read_imu(imu_dev)
    except OSError as exc:
        print(f"[sensors] MPU6050 calibration failed: {exc}")
        return 0.0, 0.0, {"x": 0.0, "y": 0.0, "z": 0.0}, False

    pitch_deg, roll_deg = accel_to_pitch_roll(accel)
    return pitch_deg, roll_deg, gyro_bias, True


def _write_power_state(
    path: str,
    battery_v: float,
    esc_overtemp_active: bool,
    esc_max_temp_c: float,
    pitch_deg: float,
    roll_deg: float,
    pitch_rate_dps: float,
    roll_rate_dps: float,
    attitude_ready: bool,
):
    payload = {
        "ts": time.time(),
        "battery_v": float(battery_v),
        "esc_overtemp_active": bool(esc_overtemp_active),
        "esc_max_temp_c": float(esc_max_temp_c),
        "pitch_deg": float(pitch_deg),
        "roll_deg": float(roll_deg),
        "pitch_rate_dps": float(pitch_rate_dps),
        "roll_rate_dps": float(roll_rate_dps),
        "attitude_ready": bool(attitude_ready),
    }
    tmp_path = f"{path}.tmp"
    try:
        with open(tmp_path, "w", encoding="utf-8") as fh:
            json.dump(payload, fh)
        os.replace(tmp_path, path)
    except Exception:
        try:
            if os.path.exists(tmp_path):
                os.remove(tmp_path)
        except OSError:
            pass



def main():
    sensor = init_bar30() if ENABLE_BAR30 else None
    imu = init_imu_with_retry() if ENABLE_MPU6050 else None
    ads = init_ads1015() if ENABLE_ADS1015 else None
    pitch_deg, roll_deg, gyro_bias, attitude_ready = _initialize_attitude_state(imu)

    print(
        f"[sensors] Sensor toggles: BAR30={'ON' if ENABLE_BAR30 else 'OFF'} "
        f"MPU6050={'ON' if ENABLE_MPU6050 else 'OFF'} "
        f"ADS1015={'ON' if ENABLE_ADS1015 else 'OFF'}"
    )

    if ENABLE_BAR30 and sensor is None:
        print("[sensors] BAR30 enabled but unavailable; publishing zeros for BAR30 fields")
    if ENABLE_MPU6050 and imu is None:
        print("[sensors] MPU6050 enabled but unavailable; publishing zeros for MPU fields")
    if ENABLE_ADS1015 and ads is None:
        print("[sensors] ADS1015 enabled but unavailable; publishing zeros for ADC fields")

    sock = socket.socket(socket.AF_INET, socket.SOCK_DGRAM)
    if USE_BROADCAST:
        sock.setsockopt(socket.SOL_SOCKET, socket.SO_BROADCAST, 1)

    target_ip = BROADCAST_IP if USE_BROADCAST else PC_IP
    print(f"[sensors] Telemetry target: {target_ip}:{PC_PORT} (broadcast={USE_BROADCAST})")
    if DEBUG:
        print(f"[sensors] PC_IP={PC_IP}, BROADCAST_IP={BROADCAST_IP}")
        print(
            "[sensors] Rates (Hz): "
            f"send={TELEMETRY_SEND_HZ}, bar30={BAR30_HZ}, mpu6050={MPU6050_HZ}, "
            f"pi_temp={PI_TEMP_HZ}, battery={BATTERY_HZ}, ads1015={ADS1015_HZ}"
        )

    send_interval = _hz_to_interval(TELEMETRY_SEND_HZ)
    bar30_interval = _hz_to_interval(BAR30_HZ)
    mpu_interval = _hz_to_interval(MPU6050_HZ)
    pi_temp_interval = _hz_to_interval(PI_TEMP_HZ)
    battery_interval = _hz_to_interval(BATTERY_HZ)
    ads_interval = _hz_to_interval(ADS1015_HZ)

    loop_sleep_s = 0.01

    telemetry = {
        "battery_v": 12.0,
        "depth_m": 0.0,
        "pressure_bar": 0.0,
        "water_temp_c": 0.0,
        "enclosure_temp_c": 0.0,
        "esc_temp_1_c": 0.0,
        "esc_temp_2_c": 0.0,
        "esc_max_temp_c": 0.0,
        "esc_overtemp_active": False,
        "pitch_deg": 0.0,
        "roll_deg": 0.0,
        "pitch_rate_dps": 0.0,
        "roll_rate_dps": 0.0,
        "attitude_ready": attitude_ready,
        "current_a": 0.0,
        "current_adc_v": 0.0,
        "pi_temp_c": 0.0,
    }

    now = time.time()
    next_send_ts = now
    next_bar30_ts = now
    next_mpu_ts = now
    next_pi_temp_ts = now
    next_battery_ts = now
    next_ads_ts = now

    last_attitude_update_ts = now
    last_imu_reconnect_try = 0.0
    last_ads_reconnect_try = 0.0
    battery_filtered_v: Optional[float] = None
    esc_overtemp_active = False

    while True:
        now = time.time()

        if now >= next_bar30_ts:
            if ENABLE_BAR30:
                pressure, temp_env, depth = read_bar30(sensor)
            else:
                pressure, temp_env, depth = 0.0, 0.0, 0.0
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

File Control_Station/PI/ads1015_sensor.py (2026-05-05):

#!/usr/bin/env python3
import math
import os
import time
from typing import Optional, Tuple

try:
    import board  # type: ignore[import-not-found]
    import busio  # type: ignore[import-not-found]
    import adafruit_ads1x15.ads1015 as ADS  # type: ignore[import-not-found]
    from adafruit_ads1x15.analog_in import AnalogIn  # type: ignore[import-not-found]
except ImportError:
    board = None
    busio = None
    ADS = None
    AnalogIn = None


ADC_ADDRESS_ENV = os.environ.get("ANGLERFISH_ADS1015_ADDR")
ADC_GAIN = float(os.environ.get("ANGLERFISH_ADS1015_GAIN", "1"))
ADC_VREF = float(os.environ.get("ANGLERFISH_ADC_VREF", "3.3"))

# Thermistor model/config
THERM_R_FIXED_OHM = float(os.environ.get("ANGLERFISH_ESC_THERM_R_FIXED_OHM", "10000"))
THERM_R0_OHM = float(os.environ.get("ANGLERFISH_ESC_THERM_R0_OHM", "10000"))
THERM_BETA = float(os.environ.get("ANGLERFISH_ESC_THERM_BETA", "3950"))
THERM_T0_C = float(os.environ.get("ANGLERFISH_ESC_THERM_T0_C", "25.0"))
THERM_TO_GND = os.environ.get("ANGLERFISH_ESC_THERM_TO_GND", "0") == "1"

# Battery and current scaling
BATTERY_DIVIDER_RATIO = float(os.environ.get("ANGLERFISH_BATTERY_DIVIDER_RATIO", "2.58"))
CURRENT_OFFSET_V = float(os.environ.get("ANGLERFISH_CURRENT_OFFSET_V", "-0.026"))
CURRENT_SCALE_A_PER_V = float(os.environ.get("ANGLERFISH_CURRENT_SCALE_A_PER_V", "25.0"))


def _candidate_ads_addresses():
    if ADC_ADDRESS_ENV:
        try:
            return [int(ADC_ADDRESS_ENV, 0)]
        except ValueError:
            print(f"[ads1015] Invalid ANGLERFISH_ADS1015_ADDR={ADC_ADDRESS_ENV!r}; using auto scan")

    # ADS1015 supports 0x48-0x4B depending on ADDR pin wiring.
    return [0x48, 0x49, 0x4A, 0x4B]


def _scan_i2c_addresses(i2c, timeout_s: float = 1.0):
    deadline = time.monotonic() + max(0.1, timeout_s)
    while not i2c.try_lock():
        if time.monotonic() >= deadline:
            return []
        time.sleep(0.01)

    try:
        return list(i2c.scan())
    except Exception:
        return []
    finally:
        i2c.unlock()


def _safe_float(value: float, fallback: float = 0.0) -> float:
    try:
        return float(value)
    except Exception:
        return fallback


def _voltage_to_therm_resistance(v_out: float) -> Optional[float]:
    v_out = _safe_float(v_out, 0.0)
    if v_out <= 0.0 or v_out >= ADC_VREF:
        return None

    if THERM_TO_GND:
        # Divider: VREF -> R_FIXED -> Vout -> THERM -> GND
        denom = ADC_VREF - v_out
        if denom <= 0.0:
            return None
        return THERM_R_FIXED_OHM * (v_out / denom)

    # Divider: VREF -> THERM -> Vout -> R_FIXED -> GND
    return THERM_R_FIXED_OHM * ((ADC_VREF / v_out) - 1.0)


def _resistance_to_temp_c(resistance_ohm: Optional[float]) -> float:
    if resistance_ohm is None or resistance_ohm <= 0.0:
        return 0.0

    t0_k = THERM_T0_C + 273.15
    try:
        inv_t = (1.0 / t0_k) + (1.0 / THERM_BETA) * math.log(resistance_ohm / THERM_R0_OHM)
        return (1.0 / inv_t) - 273.15
    except Exception:
        return 0.0


def init_ads1015():
    if None in (board, busio, ADS, AnalogIn):
        print("[ads1015] Missing dependency: install adafruit-circuitpython-ads1x15")
        return None

    try:
        i2c = busio.I2C(board.SCL, board.SDA)
        candidates = _candidate_ads_addresses()
        detected = _scan_i2c_addresses(i2c)
        if detected:
            detected_hex = ", ".join(f"0x{addr:02x}" for addr in detected)
            print(f"[ads1015] I2C devices detected: {detected_hex}")

        for addr in candidates:
            try:
                ads = ADS.ADS1015(i2c, address=addr)
                ads.gain = ADC_GAIN
                # Channel indices 0-3 work across all adafruit-ads1x15 library versions.
                channels = {
                    "ch0": AnalogIn(ads, 0),
                    "ch1": AnalogIn(ads, 1),
                    "ch2": AnalogIn(ads, 2),
                    "ch3": AnalogIn(ads, 3),
                }
                print(f"[ads1015] Initialized at 0x{addr:02x} gain={ADC_GAIN}")
                return channels
            except Exception as exc:
                print(f"[ads1015] Probe failed at 0x{addr:02x}: {exc}")

        candidates_hex = ", ".join(f"0x{addr:02x}" for addr in candidates)
        print(f"[ads1015] Init failed; no ADS1015 at [{candidates_hex}]")
        return None
    except Exception as exc:
        print(f"[ads1015] Init failed: {exc}")
        return None


def read_ads1015(channels) -> Tuple[float, float, float, float, float]:
    if channels is None:
        return 0.0, 0.0, 0.0, 0.0, 0.0

    try:
        v0 = _safe_float(channels["ch0"].voltage, 0.0)
        v1 = _safe_float(channels["ch1"].voltage, 0.0)
        v2 = _safe_float(channels["ch2"].voltage, 0.0)
        v3 = _safe_float(channels["ch3"].voltage, 0.0)

        esc_temp_1_c = _resistance_to_temp_c(_voltage_to_therm_resistance(v0))
        esc_temp_2_c = _resistance_to_temp_c(_voltage_to_therm_resistance(v1))
        battery_v = max(0.0, v2 * BATTERY_DIVIDER_RATIO)
        current_a = max(0.0, (v3 - CURRENT_OFFSET_V) * CURRENT_SCALE_A_PER_V)

        return esc_temp_1_c, esc_temp_2_c, battery_v, current_a, v3
    except Exception as exc:
        print(f"[ads1015] Read failed: {exc}")
        return 0.0, 0.0, 0.0, 0.0, 0.0

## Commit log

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2025-12-22 new file: .vscode/settings.json renamed: Controller/readme.md -> OLD/Controller/readme.md renamed: Controller/sim_360_1.0.py -> OLD/Controller/sim_360_1.0.py renamed: Controller/sim_ps5_1.0.py -> OLD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
2026-01-08 Switch ESC control to pigpio and refactor functions
    Refactor ESC control to use pigpio library and update pulse width functions.
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2026-01-08 Update ESC pulse min and max values
    Adjusted ESC pulse width limits for motors.
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2026-01-08 Refactor ESC frequency test with fixed parameters
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2026-01-29 Refactor mavlink.py to remove connection logic
    Removed the wait_conn function and connection setup code. Added a print statement to display pymavlink documentation.
2026-01-29 Modify mavlink.py for connection and control commands
    Updated connection method and added arm/disarm commands.
2026-01-29 Change connection to serial and reboot autopilot
    Updated connection method and removed arm/disarm commands.
2026-01-29 Modify mavlink.py to wait for heartbeat and print data
    Replaced autopilot reboot with heartbeat wait and added information retrieval loop.
2026-01-29 Implement vehicle arming and disarming commands
    Added functionality to arm and disarm the vehicle using MAVLink commands.
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2026-02-02 Adjust avoid range for sub motors
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2026-02-05 new file: PC/__pycache__/camera.cpython-313.pyc new file: PC/__pycache__/controller.cpython-313.pyc new file: PC/__pycache__/sensor.cpython-313.pyc new file: PC/__pycache__/xbox360_controller.cpython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
2026-03-05 modified: PC/__pycache__/controller.cpython-313.pyc modified: PC/__pycache__/sensor.cpython-313.pyc modified: PC/anglerfish.py new file: Pi/mpu6050/__init__.py new file: Pi/mpu6050/mpu6050.py
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2026-03-06 new file: PC/__pycache__/anglerfish.cpython-313.pyc modified: PC/__pycache__/camera.cpython-313.pyc modified: PC/anglerfish.py modified: PC/requirements.txt new file: Pi/__pycache__/sub_sensors.cpyth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
2026-03-11 new file: .vscode/settings.json modified: PC/__pycache__/camera.cpython-313.pyc modified: PC/__pycache__/controller.cpython-313.pyc modified: PC/__pycache__/sensor.cpython-313.pyc modified: PC/__pyca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
2026-03-16 new file: 3D/STEP/SUB_Body_Bottom.STEP new file: 3D/STEP/SUB_Body_Top.STEP new file: 3D/STL/BackPlate.STL new file: 3D/STL/Bottom_Shell.STL new file: 3D/STL/CameraMount.STL new file: 3D/STL/CenterPla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
    [BackPlate.STL, Bottom_Shell.STL, CameraMount.STL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]
2026-03-16 new file: Images/Data/assets/favicon.ico new file: Images/Data/assets/icon_viewer_full_screen-dark-24px.svg new file: Images/Data/assets/icon_viewer_min_screen-dark-24px.svg new file: Images/Data/css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
2026-03-16 deleted: Images/Data/assets/favicon.ico deleted: Images/Data/assets/icon_viewer_full_screen-dark-24px.svg deleted: Images/Data/assets/icon_viewer_min_screen-dark-24px.svg deleted: Images/Data/css/ind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
2026-03-24 modified: PC/__pycache__/camera.cpython-313.pyc modified: PC/__pycache__/controller.cpython-313.pyc modified: PC/__pycache__/sensor.cpython-313.pyc modified: PC/anglerfish.py modified: PC/camera.py m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
2026-03-25 modified: PC/anglerfish.py modified: PC/camera.py modified: PC/controller.py modified: PC/sensor.py modified: Pi/sub_motors.py modified: Pi/sub_sensors.py
2026-03-25 renamed: OLD/Controller/readme.md -> OLD/Controller1/Controller/readme.md renamed: OLD/Controller/sim_360_1.0.py -> OLD/Controller1/Controller/sim_360_1.0.py renamed: OLD/Controller/sim_ps5_1.0.py ->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
2026-03-25 deleted: PC/__pycache__/camera.cpython-313.pyc deleted: PC/__pycache__/controller.cpython-313.pyc deleted: PC/__pycache__/sensor.cpython-313.pyc deleted: PC/anglerfish.py deleted: PC/camera.py delete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
2026-03-25 new file: Controller3/Anglerfish.py new file: Controller3/PI/camera.py new file: Controller3/PI/readme.md new file: Controller3/readme.md
2026-03-25 new file: Controller3/PI/motors.py new file: Controller3/PI/mpu6050/__init__.py new file: Controller3/PI/mpu6050/mpu6050.py new file: Controller3/PI/ms5837/__init__.py new file: Controller3/PI/ms5837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
2026-03-25 modified: Controller3/Anglerfish.py new file: Controller3/PI/bar30_sensor.py new file: Controller3/PI/mpu6050_sensor.py modified: Controller3/PI/sensors.py modified: OLD/Controller2/PC/__pycache__/ca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
2026-04-02 renamed: Controller3/Anglerfish.py -> Controll_Station/Anglerfish.py renamed: Controller3/PI/ads1015_sensor.py -> Controll_Station/PI/ads1015_sensor.py renamed: Controller3/PI/bar30_sensor.py -> Cont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
2026-04-19 deleted: 3D/STEP/SUB_Body_Bottom.STEP deleted: 3D/STEP/SUB_Body_Top.STEP new file: 3D/STL/AirPod.3MF deleted: 3D/STL/BackPlate.STL deleted: 3D/STL/Bottom_Shell.STL deleted: 3D/STL/CenterPlate.STL new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
    [AirPod.3MF, BackCap.STL, BackPlate.STL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]
2026-04-21 renamed: Instructions/Schematic.pdf -> Documantation/Schematic.pdf new file: Documantation/images/bar30_3d.jpg new file: Documantation/images/camera_3d.jpg new file: Documantation/images/camera_block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
2026-04-22 deleted: Documantation/images/bar30_3d.jpg deleted: Documantation/images/camera_3d.jpg deleted: Documantation/images/camera_block.jpg deleted: Documantation/images/controler_diagram.jpg deleted: Docu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
2026-05-05 modified: Controll_Station/PI/ads1015_sensor.py modified: Controll_Station/PI/camera.py modified: Controll_Station/PI/sensors.py new file: Test_Station/Anglerfish.py new file: Test_Station/PI/ads1015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

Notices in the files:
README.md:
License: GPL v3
